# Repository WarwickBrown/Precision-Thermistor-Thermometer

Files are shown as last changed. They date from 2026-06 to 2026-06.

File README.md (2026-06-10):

# Precision Thermistor Thermometer

A two-channel, sub-millikelvin-class temperature measurement and logging
instrument built around a Raspberry Pi Pico W and a 16-bit ADS1115 ADC, using
matched 100 kΩ NTC thermistors in differential Wheatstone half-bridges.

It was developed as the instrumentation for a passively temperature-stabilised
enclosure used in a photonic reservoir-computing experiment. In that experiment
a multimode fibre acts as the nonlinear mixing medium, and its refractive index
(and therefore the computation it performs) is temperature-sensitive.
Characterising and controlling that thermal environment is what this instrument
is for.

The work is part of an MSc (Electrical Engineering) research project at the
University of the Witwatersrand, supervised by Prof. Mitchell Cox. The research
title is not finalised yet.

> **Status: v1.0.** A working two-channel instrument on soldered stripboard,
> housed in a 3D-printed enclosure. The thermistors are characterised, the two
> channels are matched, and a bonded-probe run shows the A−B difference holding to
> about 0.5 to 0.8 mK, with each probe to about 0.5 mK. See
> [Project status](#project-status).

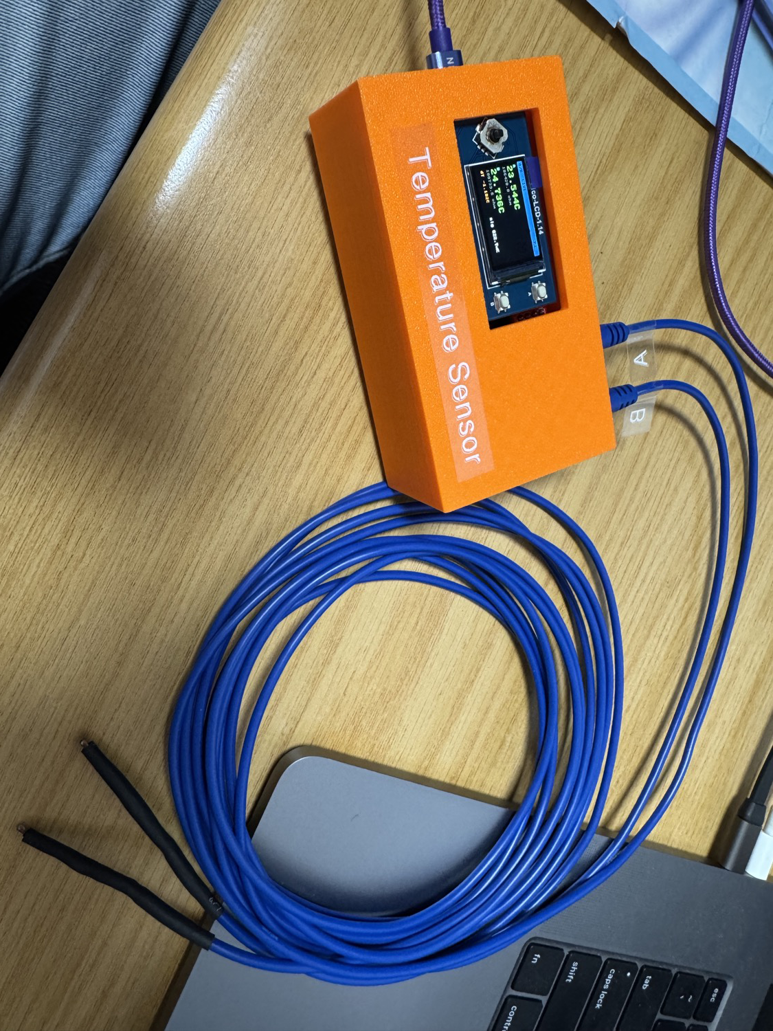
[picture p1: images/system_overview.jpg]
Two-channel thermistor thermometer


*Pico W and ADS1115 differential front-end with a Pico-LCD-1.14, soldered onto
stripboard, with both NTC probes on shielded cable.*

---

## Why this design

The goal was to find out, cheaply, how much temperature resolution is actually
achievable with a commodity 16-bit ADC before committing to a more complex and
more expensive 24-bit sigma-delta design (the ADS1220). Rather than assume the
24-bit part is necessary, this project proves out the 16-bit approach end to end
and measures its real noise floor.

The design decisions and the reasoning behind them are written up in
[`docs/design_notes.md`](docs/design_notes.md).

---

## How it works

```
            +3V3 (or ADC_VREF)
                 │
     ┌───────────┴───────────┐         (one half-bridge per channel)
     │                       │
    R_a (100k)              R_top (100k)
     │                       │
   NODE_A ───► AINP        NODE_B ───► AINN     ADS1115 reads (AINP − AINN)
     │                       │                  differentially, PGA-amplified
    R_b (100k)              NTC (100k, on cable)
     │                       │
    GND                     GND
```

* Each thermistor sits in its own differential half-bridge. The bridge output
  is about 0 V at balance (around 25 °C), so the ADC's smallest range
  (±0.256 V, PGA = 16) can be used for maximum resolution around the operating
  point.
* The ADS1115 has two differential pairs, so two probes are read: channel 1 is
  AIN0−AIN1 and channel 2 is AIN2−AIN3.
* Resistance is recovered from the measured differential voltage and then
  converted to temperature with a narrow-range B-model fit (see
  [Calibration](#calibration)).
* A Waveshare Pico-LCD-1.14 provides a multi-page live UI. Readings also stream
  as CSV over USB serial for logging.

### Resolution (theoretical)

| Quantity | Value |
|---|---|
| Bridge sensitivity (V_exc = 3.3 V) | ≈ 36.6 mV/K |
| ADS1115 LSB at PGA = 16 (±0.256 V) | 7.81 µV |
| **Resolution** | **≈ 0.21 mK / LSB** |
| Usable span at PGA = 16 | ≈ ±7 K around bridge balance |

These figures are derived and verified by round-trip simulation in
[`docs/design_notes.md`](docs/design_notes.md). The full error budget, which
separates the theoretical precision (tens of µK) from the reference-limited
absolute accuracy (about 0.1 °C), is in
[`docs/error_budget.md`](docs/error_budget.md).

---

## Measured performance

> Numbers marked _(prelim.)_ are early bench observations rather than a rigorous
> characterisation. The stability rows are from the bonded-probe calibration run.

| Metric | Value | Notes |
|---|---|---|
| Single-shot noise, settled (breadboard) | ~±4 mK p-p _(prelim., eyeballed)_ | continuous excitation, no RC filter |
| Rolling σ (32-sample), simulated 3 mK input | ~2.4 mK | sanity check of stats pipeline |
| Thermistor B-value match (A vs B) | 0.1 % | 3816.6 K vs 3820.8 K |
| Thermistor R₀ match (A vs B) | 0.3 % | ~99.9 kΩ vs ~99.6 kΩ at 25 °C |
| Absolute accuracy | ~0.1 °C | limited by reference probe (UNI-T UT71B) |
| Single-channel noise (1σ, single sample) | ~0.4 to 0.6 mK _(calibration run)_ | A ~0.6, B ~0.4, box drift removed |
| Differential A−B stability (Allan) | ~0.5 to 0.8 mK _(calibration run)_ | bonded probes, see [calibration results](docs/calibration/calibration_run_results.md) |
| Absolute long-term stability | reference-limited | bounded by the thermal environment and reference resistors, not the ADC |

A note on accuracy versus precision. The ~0.1 °C absolute figure is set by the
reference thermometer used during calibration. The instrument's relative
stability, which is the quantity that matters for thermal control, is far better.
The bonded-probe run shows the A−B difference holding to about 0.5 to 0.8 mK and
each probe to about 0.5 mK (see the
[calibration results](docs/calibration/calibration_run_results.md)). Pushing the
absolute single-channel figure lower would need a more stable thermal reference
than was available, since it is bounded by the environment rather than the ADC.

---

## Repository layout

```
precision-thermistor-thermometer/
├── README.md                 ← this file
├── LICENSE
├── CITATION.cff              ← how to cite this work
├── run.sh                    ← host helper: setup, flash, log, analyse
├── firmware/                 ← MicroPython for the Pico W
│   ├── config.py             ← all tunable constants (QUIET/FAST profiles, calibration)
│   ├── ads1115.py            ← minimal differential ADS1115 driver
│   ├── bridge.py             ← bridge maths + B-model / Steinhart-Hart
│   ├── sampling.py           ← runtime QUIET/FAST sampling-profile switch
│   ├── ds18b20_reader.py     ← optional 1-Wire ambient sensor
│   ├── lcd_1inch14.py        ← Waveshare Pico-LCD-1.14 driver (bundled)
│   ├── display.py            ← multi-page LCD UI (KEY A/B navigated)
│   └── main.py               ← measurement loop (USB + flash CSV logging)
├── hardware/
│   ├── ADS1115BasicDesign.*  ← KiCad schematic + BOM (draws an optional DS18B20 not fitted here)
│   ├── schematic_bridge.png  ← bridge + ADC front-end
│   ├── netlist.md            ← full from-to netlist
│   └── bom.md                ← bill of materials
├── docs/
│   ├── user_manual.md        ← how to run the device (screens, buttons, output)
│   ├── design_notes.md       ← design rationale + noise budget
│   ├── error_budget.md       ← theoretical accuracy vs precision, full budget
│   ├── calibration_procedure.md ← how to calibrate and match the two channels
│   ├── characterisation.md   ← thermistor calibration write-up
│   ├── calibration/          ← (T,R) sweep, fit workbook, channel-matching run + results
│   └── build_log.md          ← chronological bring-up / debugging notes
├── tools/
│   ├── serial_logger.py      ← capture the USB CSV stream to a host file (+ live plot)
│   ├── analyse_log.py        ← off-Pico stability / Allan-deviation analysis
│   └── requirements.txt      ← host-side Python dependencies
├── enclosure/                ← 3D-printed cover (Fusion 360 + STEP + STL)
│   ├── cover.f3d
│   ├── cover.step
│   └── cover.stl
├── data/                     ← logged runs (CSV)
└── images/                   ← photos, screenshots
```

---

## Quick start

1. Flash MicroPython for the Pico W (the `.uf2` from micropython.org).
2. Copy everything in [`firmware/`](firmware/) to the Pico's root. The Waveshare
   `lcd_1inch14.py` driver is bundled, so nothing else needs downloading. Thonny
   works, but `mpremote` copies the whole folder in one go
   (`mpremote connect auto cp firmware/*.py :` then `mpremote reset`), and
   `mpremote mount firmware` runs the code straight off your computer while you
   develop, with no copying.
3. Edit [`firmware/config.py`](firmware/config.py): set your measured excitation
   voltage, per-channel resistor values, and thermistor coefficients. Choose a
   boot `MODE`. `'logging'` starts in the quiet, roughly 1 mK QUIET profile and
   `'live'` starts in the fast FAST profile. You can switch between them at any
   time by long-pressing the joystick (see [Sampling profiles](#sampling-profiles)).
4. Reset the Pico. `main.py` runs automatically. Readings appear on the LCD,
   stream as CSV over USB serial, and, when `LOG_TO_FLASH` is set, are appended
   to `log.csv` on the Pico's flash so a run survives a USB disconnect.
5. Capture a run live on the computer with
   [`tools/serial_logger.py`](tools/serial_logger.py), or pull `log.csv` off the
   Pico's flash. Then analyse stability with
   [`tools/analyse_log.py`](tools/analyse_log.py) (see
   [Logging and analysis](#logging-and-analysis)).

The chronological bring-up, including the debugging dead-ends, is in
[`docs/build_log.md`](docs/build_log.md).

---

## Host tools (one-time setup)

The off-Pico steps (uploading the firmware, capturing, plotting, analysis) are
wrapped by [`run.sh`](run.sh), which keeps their Python dependencies in a
self-contained `.venv` so nothing is installed into your system Python:

```
./run.sh setup                          # once: create .venv and install the tools
./run.sh flash                          # copy firmware/ to the Pico and reboot it
./run.sh log                            # capture the USB CSV into data/ (Ctrl-C to stop)
./run.sh log --plot                     # ... and draw a live chart
./run.sh analyse data/log_YYYY..._.csv  # stability / Allan-deviation analysis
./run.sh pull-log                       # copy the Pico's flash log.csv into data/
./run.sh clear-log                      # wipe the Pico's flash log.csv (asks first)
```

Only one program can use the USB port at a time, so close Thonny or any serial
monitor before `flash` or `log`. The tools under [`tools/`](tools/) can also be
run directly if you prefer (Windows users without bash can create the venv with
`python -m venv .venv` and `pip install -r tools/requirements.txt`).

---

## The display

New to the device? The [user manual](docs/user_manual.md) walks through the
screens, the buttons, the update cadence, and how to read the data on a
connected computer.

Five pages, moved through with **KEY A** (next) and **KEY B** (previous). The
joystick LEFT / RIGHT pages too, as a backup.

| Page | Shows |
|---|---|
| **LIVE** | Both probes in large type: temperature, resistance, ΔT, rolling σ |
| **AVERAGES** | Rolling mean over a short and a long window, per probe, plus A−B |
| **TREND** | Scrolling chart of A and B temperature (shared autoscale) |
| **DELTA** | Scrolling chart of A−B (common-mode-cancelled, most sensitive) |
| **STATS** | Mean, σ, min-max span, drift rate, STABLE/SETTLING flag |

The rest of the controls sit on the joystick. UP cycles the backlight (full,
dim, off), which matters because the backlight is a heat source near the
sensors. DOWN resets the statistics and history. A short press of the joystick
centre toggles a hold/freeze, and a long press switches the sampling profile
live (see [Sampling profiles](#sampling-profiles)).

<p align="center">
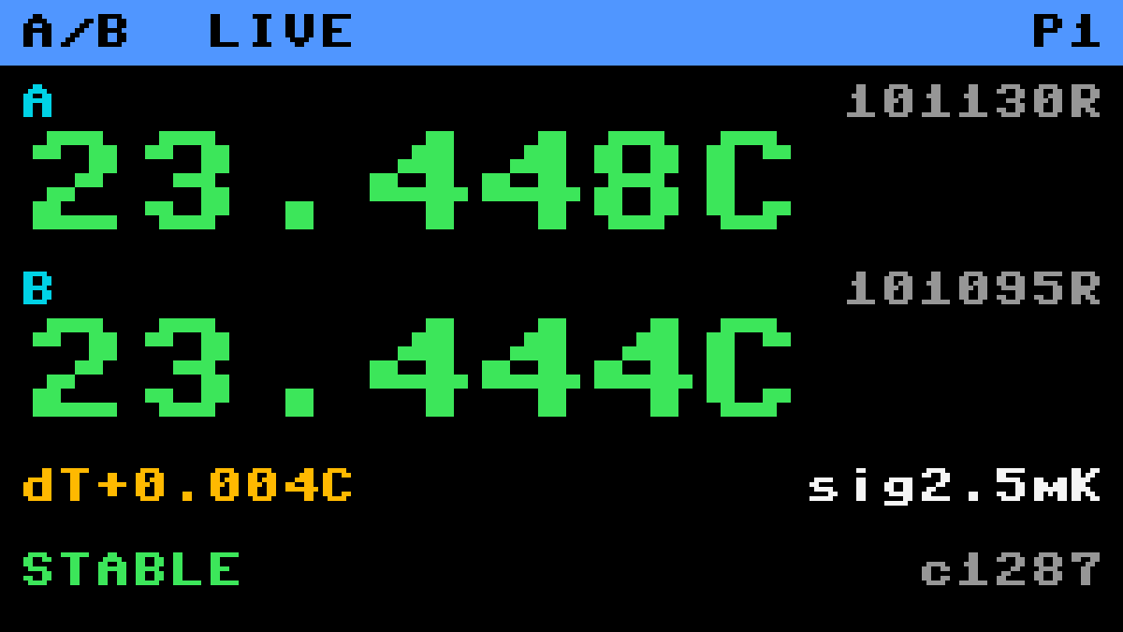
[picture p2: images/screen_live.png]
LIVE page
  
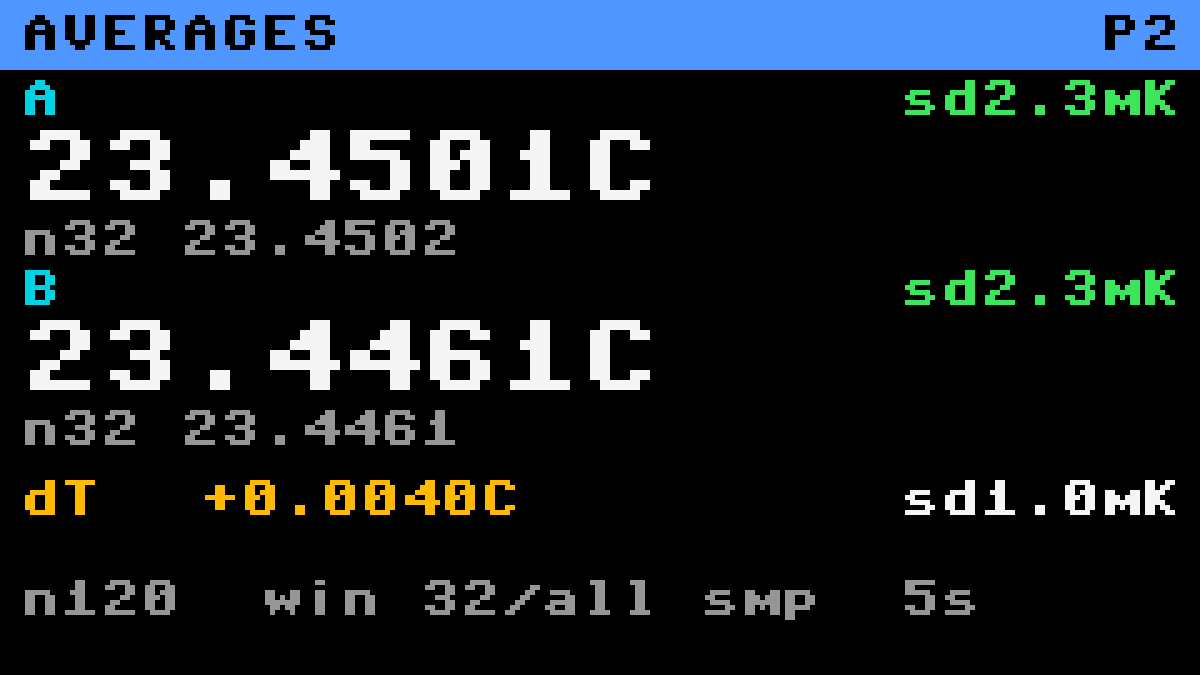
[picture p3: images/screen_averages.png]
AVERAGES page
  
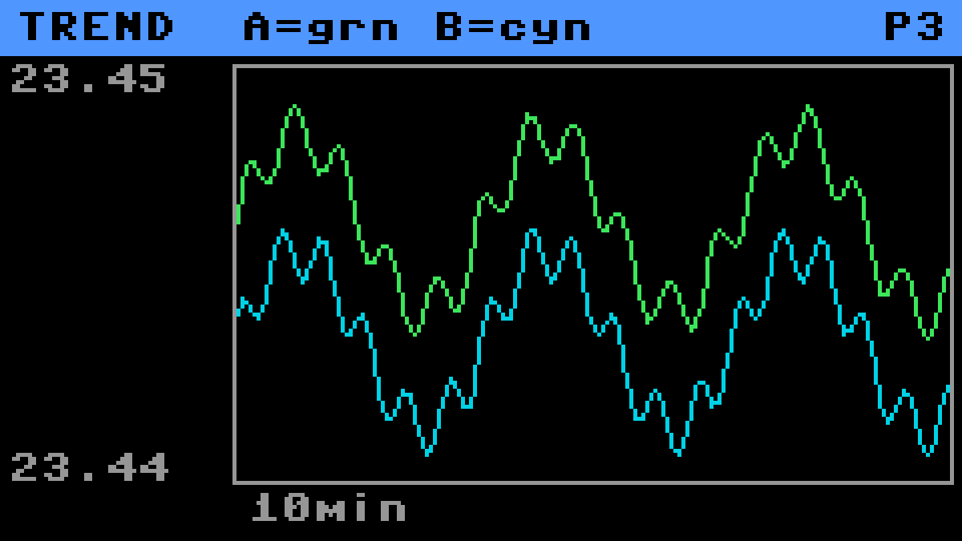
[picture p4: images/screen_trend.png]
TREND page
  
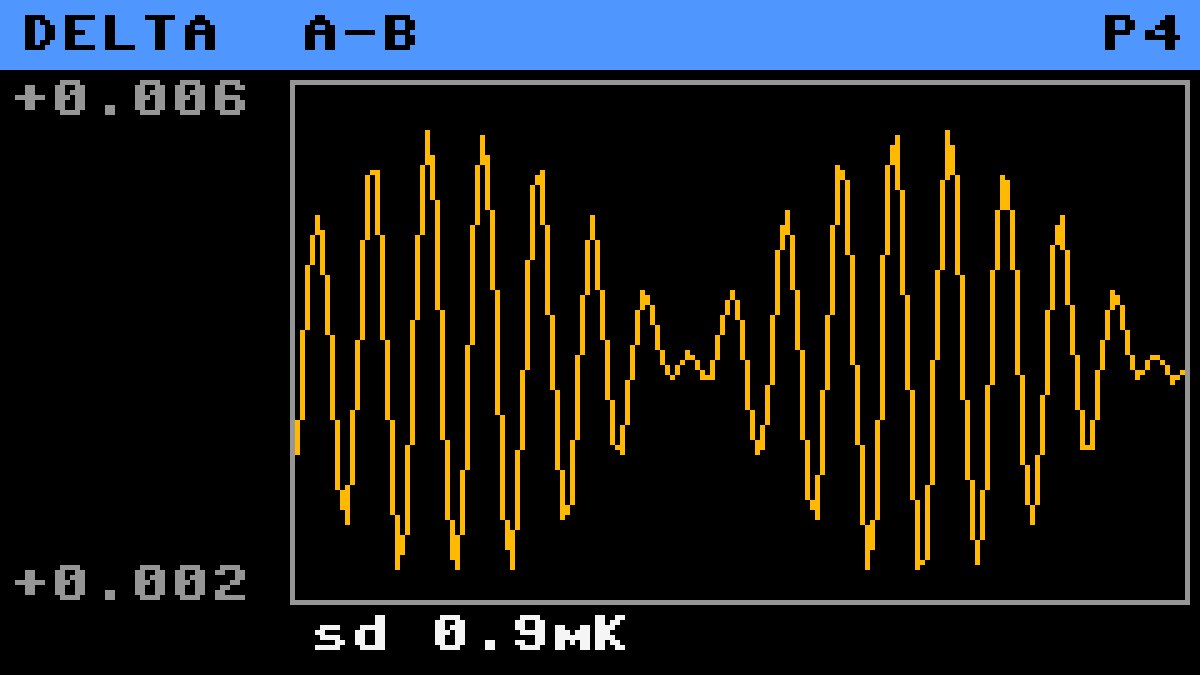
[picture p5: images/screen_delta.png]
DELTA page
  
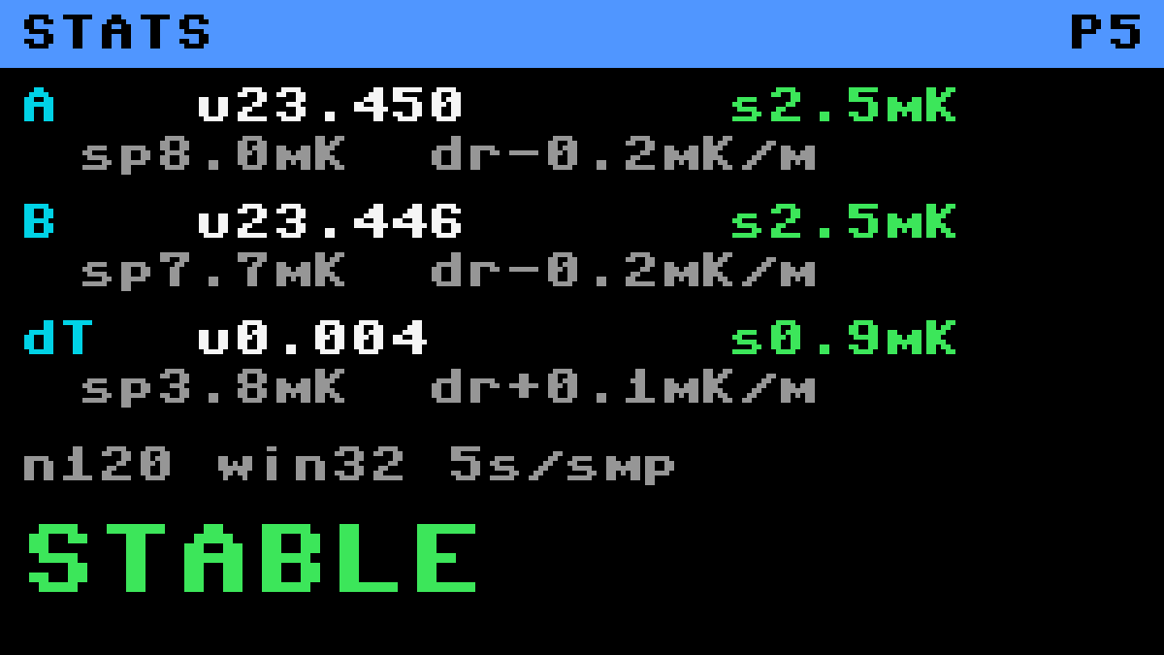
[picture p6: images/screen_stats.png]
STATS page
  
</p>

*The LIVE, AVERAGES, TREND, DELTA and STATS pages, rendered from the firmware
display layout using the panel's own 8x8 font, so they match the LCD pixel for
pixel. The values shown are illustrative.*

## Sampling profiles

The instrument carries two sampling profiles and switches between them at
runtime, with no reflash, by long-pressing the joystick centre. A FAST badge
shows in the header when the fast profile is active.

| Profile | Averages | Rate | PGA | Cycle | For |
|---|---|---|---|---|---|
| **QUIET** | 16 | 8 SPS | ±0.256 V | 5 s | the quiet, roughly 1 mK logging setup |
| **FAST** | 4 | 475 SPS | ±2.048 V | 0.2 s (≈5 Hz) | watching the screen in near real time |

`config.MODE` chooses which one is active at boot. Both profiles are defined in
[`firmware/config.py`](firmware/config.py), so the averages, rate, range, cycle
time, and settle wait of either can be tuned there. To go faster than 5 Hz, lower
the FAST `period_s` toward about 0.1.

---

## Logging and analysis

Each cycle the firmware emits one CSV row, both over USB serial and, when
`LOG_TO_FLASH` is set, appended to `log.csv` on the Pico's flash. The columns
are:

```
cycle, t_s, vdiff1_uv, r1_ohm, t1_c, vdiff2_uv, r2_ohm, t2_c, t_amb_c
```

The serial stream is the easy way to capture a run straight onto the connected
computer in real time. `serial_logger.py` auto-detects the Pico's port, saves a
timestamped file under `data/`, appends a `host_time` wall-clock column to each
row so the data lines up with other measurements, and can draw a live chart:

```
python tools/serial_logger.py            # capture to data/, echo to screen
python tools/serial_logger.py --plot     # also show a live temperature chart
```

The capture runs as long as you like and reconnects on its own if the USB drops,
while the live chart keeps a rolling window of recent points. The flash log is
the backup that survives a USB disconnect. Either way, copy the
resulting CSV onto a computer and run the off-Pico analysis tool:

```
python tools/analyse_log.py log.csv --settle-min 10
```

It prints per-channel statistics (mean, σ, peak-to-peak, drift), the
common-mode-cancelled A−B difference channel, and an overlapping Allan deviation
against averaging time τ. The minimum of the Allan curve is the headline number
for this project. It gives the best achievable stability and the averaging time
that reaches it, which is the direct answer to the question "is 16-bit enough?".
The tool needs `numpy` and `matplotlib`.

---

## Calibration

Thermistors are characterised individually against a UNI-T UT71B reference and
then fitted with a two-parameter B-model tuned for the 10 to 30 °C operating range:

```
T(°C) = B / (ln R − intercept) − 273.15
```

| Probe | B (K) | intercept | R₀ @ 25 °C |
|---|---|---|---|
| A (NTC-01) | 3816.56 | −1.288504 | ~99.9 kΩ |
| B (NTC-02) | 3820.82 | −1.306170 | ~99.6 kΩ |

For relative precision you usually do not need that absolute calibration, or a
reference thermometer at all. You only need the two channels to agree when both
probes are at the same temperature. Bond the probe beads together, let them
settle, read the steady A−B on the AVERAGES screen, and set the per-channel
`CH1_T_OFFSET` / `CH2_T_OFFSET` trims to zero it. The full step-by-step is in
[`docs/calibration_procedure.md`](docs/calibration_procedure.md). On this build
the channels are already matched: a bonded-probe run measured A−B at +133.5 mK,
now trimmed to within 0.1 mK (see
[calibration results](docs/calibration/calibration_run_results.md)).

The absolute method, residuals, and raw sweep data are in
[`docs/characterisation.md`](docs/characterisation.md) and
[`docs/calibration/`](docs/calibration/) (fit workbook
`V2_Thermistor_Measurement.xlsx`).

---

## Project status

- [x] Differential bridge + ADS1115 front-end designed and simulated
- [x] Single-channel bring-up on breadboard
- [x] Two-channel (Option C) differential operation
- [x] Thermistor characterisation (B-model)
- [x] Channel matching (A−B offset trimmed from a bonded-probe run)
- [x] Soldered onto stripboard with RC input filters + star ground
- [x] Multi-page LCD UI
- [x] On-Pico flash logging + off-Pico Allan-deviation analysis tool
- [x] 3D-printed enclosure modelled and printed (fit being refined)
- [x] Differential stability measured (A−B sub-millikelvin, bonded-probe run)
- [x] 16-bit confirmed sufficient for the differential measurement, so the ADS1220 is not needed

The absolute long-term stability is bounded by the thermal environment and the
reference resistors rather than the ADC, so characterising it below the drift of
the box used here would require a more stable reference.

---

## Future improvements

Out of scope for v1.0, but worth noting:

- **Pulsed excitation** with a logic-level PMOS, to cut the ~27 mK self-heating
  offset (deferred because only a non-logic-level part was available, see the
  [design notes](docs/design_notes.md)).
- **Absolute single-channel stability** characterisation, which would need a
  thermal reference more stable than the box used here.
- **Per-channel absolute recalibration** against a better reference, to improve
  the ~0.1 °C absolute accuracy.
- **WiFi/NTP timestamps** on the Pico W, so the standalone flash log carries
  absolute time without the host capture.

---

## License

MIT. See [LICENSE](LICENSE).

## Acknowledgements

Built at the University of the Witwatersrand as part of an MSc (Electrical
Engineering) project supervised by Prof. Mitchell Cox, as the instrumentation
for a photonic reservoir-computing experiment. The 3D-printed enclosure was
designed by Matthew Maccelari. The firmware and circuit were developed
iteratively on the bench. See [`docs/build_log.md`](docs/build_log.md) for the
full bring-up story, including the debugging dead-ends.

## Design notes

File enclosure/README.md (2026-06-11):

# Enclosure

3D-printed cover for the instrument (Pico + LCD + stripboard), designed by
**Matthew Maccelari**.

Source CAD and meshes:

| File | Format |
|---|---|
| `cover.f3d` | Fusion 360 source |
| `cover.step` | portable STEP solid (for other CAD tools) |
| `cover.stl` | mesh, ready to slice and print |

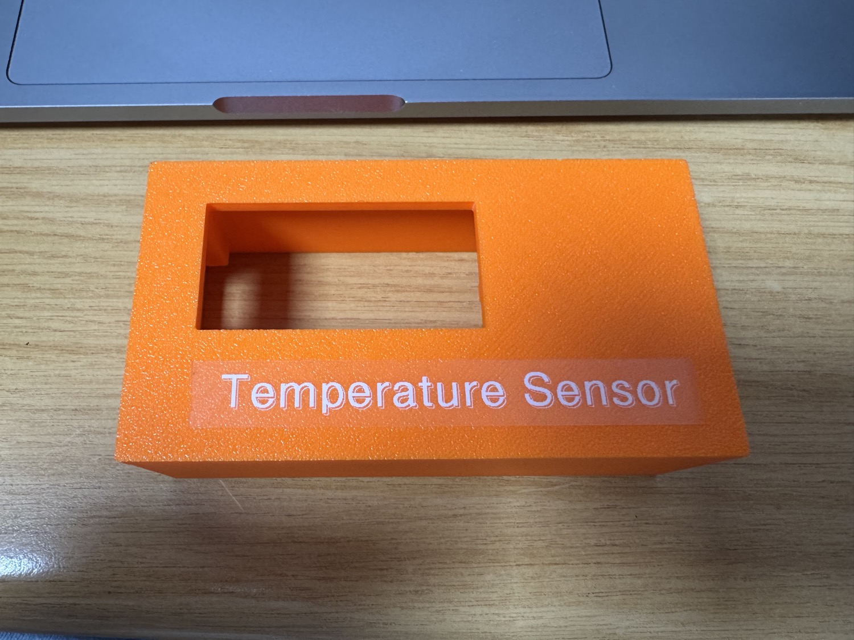
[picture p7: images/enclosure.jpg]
3D-printed enclosure, top with the LCD window and label


<p align="center">
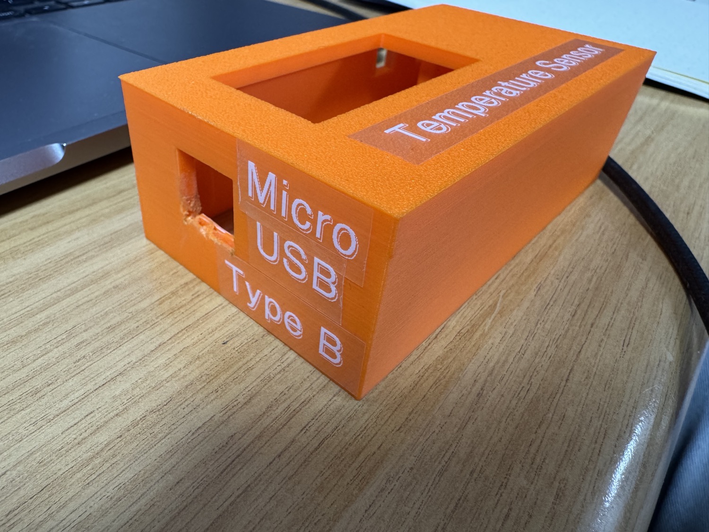
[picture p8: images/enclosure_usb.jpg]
USB Type-B port side
  
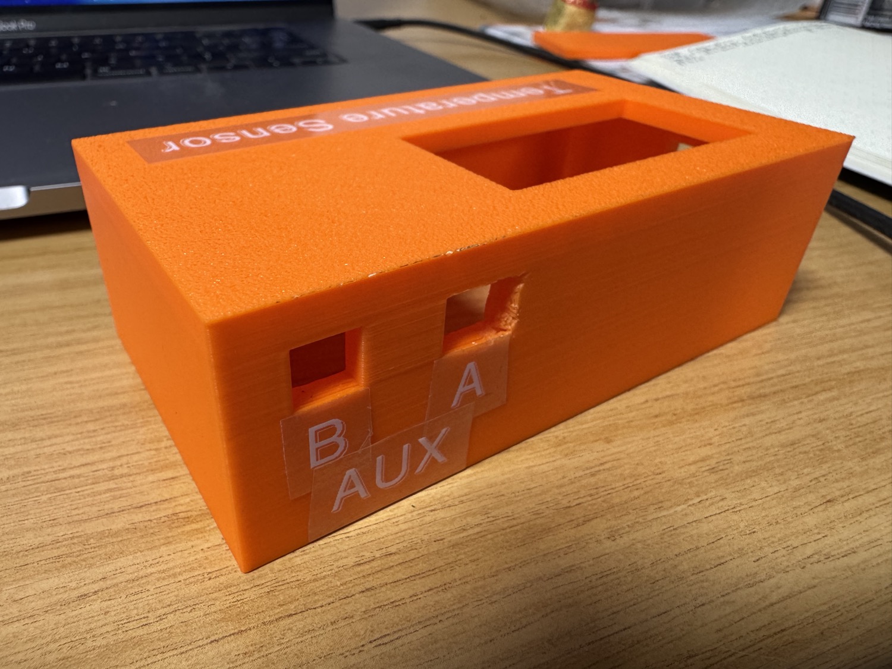
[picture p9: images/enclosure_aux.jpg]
AUX side with A / B probe jacks
  
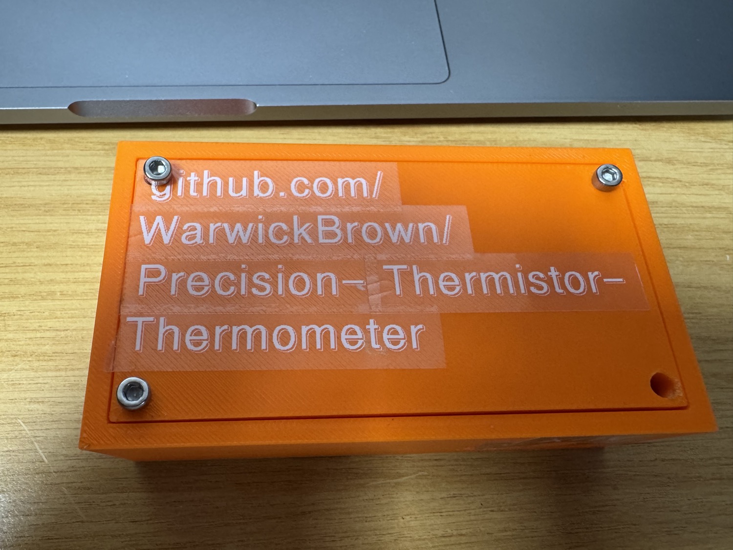
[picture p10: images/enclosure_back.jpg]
base, engraved with the repo URL
  
</p>

*USB side, the labelled A / B AUX jacks, and the engraved base.*

## Note

The 3D print is not perfect and adjustments need to be manually made to the hole sizes when fitting the circuit board into the enclosure.

M3 10mm hole inserts should be sunk into the plastic and M3 20mm bolts can be used to screw it all down.

## Design considerations

- **LCD on the lid**, board inside, which keeps the screen visible while the
  sensors stay enclosed.
- **Backlight heat:** the LCD backlight is the largest local heat source. Keep
  it physically away from the thermistor cable entries, and note the firmware
  can dim/disable the backlight (KEY A) during sensitive runs.
- **Cable pass-throughs** for the two thermistor leads (audio jacks) and USB.
- **Non-enclosed reference-resistor cluster** sits with the warm digital
  section, because thermal gradients across the bridge resistors appear as
  measurement error.
- **Female AUX daughter board supports** have been added so that the small boards do not flex. Glue the blocks onto the Veroboard and Prestik them to the top so the boards don't move. A support has been added behind the boards to support the insert force.

Most recent CAD file uploaded 11/06/2026 (v3)

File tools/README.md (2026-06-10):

# Tools

Off-Pico helpers that run on a normal computer rather than on the
microcontroller. Install their dependencies once with:

```
pip install -r tools/requirements.txt
```

## `serial_logger.py`

Captures the CSV the firmware streams over USB serial straight onto the host
computer. It auto-detects the Pico's serial port, echoes the stream to the
screen, and saves it to a timestamped file in `data/` that you can then feed to
`analyse_log.py`. Each row gets a `host_time` wall-clock column appended (last
field) so the data can be matched to other measurements taken on the same
computer. With `--plot` it also draws a live temperature chart. Needs `pyserial`
(and `matplotlib` only for `--plot`).

```
python tools/serial_logger.py                 # auto-detect port, save to data/
python tools/serial_logger.py --list          # list serial ports and exit
python tools/serial_logger.py --port COM5     # choose the port yourself
python tools/serial_logger.py --plot          # also draw a live chart
python tools/serial_logger.py --plot-points 6000  # keep more points on the chart
python tools/serial_logger.py --out run1.csv  # choose the output file
python tools/serial_logger.py --no-file       # echo only, do not save
python tools/serial_logger.py --no-timestamp  # do not append host_time
```

Notes:

* The capture is unlimited. It runs until you stop it with Ctrl-C, bounded only
  by disk space, and it reconnects on its own if the USB drops or the Pico
  resets, carrying on into the same file.
* The live chart shows a rolling window of the most recent points
  (`--plot-points`, default 3000) so memory and redraw stay flat over long runs.
  Everything is still saved to the file regardless of what the chart shows.
* The appended `host_time` column does not disturb `analyse_log.py`, which reads
  only the fixed firmware columns and ignores the extra field.
* The Pico's own flash log has no `host_time`, only the data and `t_s`, so it
  stays compact. Absolute time comes from this host capture.

This complements the on-Pico flash log. The flash log survives a USB
disconnect, while the serial capture is the easy way to pull a long run onto the
computer in real time.

### If it is not writing to the file

Run it from the VS Code integrated terminal (`python tools/serial_logger.py`),
not the Run button, so you can see the output and press Ctrl-C to stop cleanly.
The tool prints the absolute save path on startup (`saving: ...`), which by
default is this repo's `data/` folder, not your current directory.

* **Nothing scrolls and the file ends up empty.** No data is reaching the
  computer. Only one program can hold a serial port at a time, so close Thonny,
  the VS Code MicroPico or Serial Monitor extension, and any other REPL first.
  Then reset the Pico so `main.py` is actually running and streaming, rather than
  sitting at the REPL. The tool now prints a hint if it connects but sees no data
  within five seconds.
* **"This tool needs pyserial".** Install it into the same interpreter VS Code is
  using. In the VS Code terminal run `python -m pip install pyserial` (or
  `pip install -r tools/requirements.txt`), making sure the interpreter shown in
  the terminal prompt is the one the Run button uses.

## `analyse_log.py`

Stability analysis for the CSV the firmware produces (`log.csv`, a flash dump,
or a `serial_logger.py` capture). It reports per-channel statistics, the
common-mode-cancelled A-B difference channel, and the overlapping Allan
deviation against averaging time tau. The minimum of that curve answers the
project's central question, "is 16-bit enough?". Needs `numpy` and `matplotlib`.

```
python tools/analyse_log.py log.csv                 # stats + Allan plot -> stability.png
python tools/analyse_log.py log.csv --settle-min 10 # drop the first 10 min (warm-up)
python tools/analyse_log.py log.csv --col t1_c      # analyse a single column
python tools/analyse_log.py log.csv --no-plot       # stats only
```

The expected CSV columns are:

```
cycle, t_s, vdiff1_uv, r1_ohm, t1_c, vdiff2_uv, r2_ohm, t2_c, t_amb_c
```

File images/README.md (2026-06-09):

# Images

Photos and screenshots used in the documentation.

## System photos

| File | Shot |
|---|---|
| `system_overview.jpg` | finished instrument in its enclosure with both probe cables (README hero) |
| `lcd_live.jpg` | the soldered stripboard build (Pico W, ADS1115, probes), with the earlier UI on screen |
| `probes.jpg` | the two NTC probe leads (tinned inner conductors of the shielded cable) |

## Screen renders

Rendered from the firmware display layout (`firmware/display.py`) using the
panel's own 8x8 font, so they match what the LCD shows pixel for pixel. The
values are illustrative. These replace the earlier screen photos, which were of
the previous smaller-font UI.

| File | Page |
|---|---|
| `screen_live.png` | LIVE, both probes large: T, R, ΔT, rolling σ |
| `screen_averages.png` | AVERAGES, rolling means over a short and a long window |
| `screen_trend.png` | TREND, scrolling A/B temperature chart |
| `screen_delta.png` | DELTA, scrolling A−B difference |
| `screen_stats.png` | STATS, mean, σ, span, drift, STABLE/SETTLING flag |

## Enclosure

| File | View |
|---|---|
| `enclosure.jpg` | top / lid, with the LCD window and "Temperature Sensor" label |
| `enclosure_usb.jpg` | USB Type-B port side |
| `enclosure_aux.jpg` | AUX side with the labelled A / B probe jacks |
| `enclosure_back.jpg` | base, engraved with the repository URL |

The calibration workbook lives under
[`../docs/calibration/`](../docs/calibration/). A bath/UT71B setup photo and a
residuals plot can be added there later. See that folder's README.

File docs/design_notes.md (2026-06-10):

# Design notes

The reasoning behind the circuit and firmware choices. This is the "why" rather
than the "how". See the README for usage and `build_log.md` for the
chronological bring-up.

## Goal

Determine how much temperature resolution a commodity 16-bit ADS1115 can deliver
in a thermistor bridge before committing to a 24-bit ADS1220. The worry is that
a 24-bit part may not yield usable extra bits once real-world noise is accounted
for, so the cheaper option is validated first.

## Sensor choice: 100 kΩ NTC

* High resistance means lead and contact resistance are negligible. A 1 m cable
  at about 0.2 Ω is roughly 2 ppm of a 100 kΩ sensor, so no Kelvin or 4-wire
  sensing is needed.
* Large dR/dT, about −4400 Ω/K near 25 °C (B ≈ 3820 K), gives strong
  sensitivity.

## Topology: differential half-bridge

Each probe sits in a half-bridge, and the ADC reads the difference between the
sense node and a reference node.

```
dV/dT ≈ (V_exc / 4) · (B / T²) ≈ V_exc · 11.1 mV/K
      ≈ 36.6 mV/K at V_exc = 3.3 V
```

Reading differentially (AINP − AINN) rather than single-ended does three things:

* it rejects excitation-supply noise as common-mode,
* it keeps the signal near 0 V at balance so PGA = 16 (±0.256 V) can be used,
* it uses the ADS1115's full ±32768 signed range.

## Noise / resolution budget

| Quantity | Value |
|---|---|
| LSB at PGA = 16 | 7.81 µV |
| ADS1115 input-referred noise (8 SPS) | ~2 µV RMS |
| Bridge sensitivity | 36.6 mV/K |
| **Resolution** | **0.21 mK / LSB** |
| **Noise floor (single sample)** | **~55 µK RMS** |
| Span at PGA = 16 | ±7 K around balance |

So resolution and the white-noise floor are comfortably sub-mK. The ~55 µK above
is the ADC-noise component alone. The combined single-sample floor including
quantisation is about 85 µK, and the full budget with the measured results is in
[`error_budget.md`](error_budget.md). The real limits are self-heating,
reference-resistor drift, and layout/EMI, which are addressed below.

## Excitation: continuous DC (pulsing deferred)

Pulsed excitation was planned to cut thermistor self-heating, switched by a
high-side PMOS. The only available PMOS was an IRFD9024, a standard-threshold
part rather than a logic-level one. At 3.3 V gate drive it never fully enhances
and sits in its linear region with a large, temperature-dependent on-resistance.
That would inject drift into V_exc that mimics a temperature signal, which is
worse for precision than the problem it solves.

The decision was to run continuous excitation. Self-heating (about 27 mK at
3.3 V across the sense leg) is a constant offset that calibration absorbs. It
only harms precision if the dissipation-to-environment coupling fluctuates,
which it does not inside the still air of the enclosure. Pulsing can be
revisited later with a proper logic-level PMOS. To reduce self-heating passively
without a switch, a series dropper resistor can lower V_exc (around 10x less
dissipation at about 1 V) at the cost of some sensitivity.

## Ratiometric-ish reference

The bridge is excited from the Pico's filtered `ADC_VREF` pin (or 3V3). The
ADS1115 has a fixed internal reference, so the measurement is not fully
ratiometric. True ratiometric operation (external VREF tied to the excitation)
is a reason to move to the ADS1220 later.

## Front-end filtering

A differential RC filter sits at each ADC input: 1 kΩ in series per line plus a
100 nF differential cap across the pair, with optional 10 nF common-mode caps to
ground. The corner is about 800 Hz, far above the thermal signal bandwidth and
far below mains hum, RF, and digital switching. The 1 kΩ is kept small so the
ADS1115's finite PGA input impedance (about 700 kΩ at PGA = 16) introduces only
a fraction of a percent of scale error, which calibration removes anyway. A
larger series R would interact badly with the switched-cap input.

## Grounding

Star ground: analog returns (bridge bottoms, ADC GND, decoupling, filter caps)
on one strip, digital returns (Pico, LCD, I²C) on another, and the two joined by
a single jumper at the ADS1115 GND pin. On stripboard, strip resistance (about
5 mΩ per 30 mm) means shared digital return current would inject µV-level errors
into the analog reference, which is why the two are kept separate.

## Calibration model

A two-parameter B-model over the operating range is used rather than full-range
Steinhart-Hart. It gives better residuals in the operating window, because the
extreme-temperature bath points were taken under non-equilibrium conditions and
added scatter, and it inverts trivially. Both models are implemented in
`bridge.py`, and `config.TEMP_MODEL` selects between them.

## Verification

The bridge inverse-maths and resolution were checked by round-trip simulation:
pick a true NTC resistance, compute the differential voltage the ADC would see,
run it back through the firmware maths, and confirm recovery. The firmware's
B-model and Steinhart-Hart conversions were checked against the characterisation
spreadsheet's own predicted temperatures and matched to the third decimal.

The common-mode rejection was later measured on a bonded-probe run: as the box
drifted about 190 mK, the A−B difference held to a sigma of 3 mK, roughly 18
times below either channel alone, confirming the design intent. See
[`calibration/calibration_run_results.md`](calibration/calibration_run_results.md).

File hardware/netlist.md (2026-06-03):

# Netlist (from-to)

Two-channel differential bridge (Option C), continuous excitation, breakout
ADS1115, RC input filters, and audio-jack thermistor connectors. Each row is a
net. Nets with more than two endpoints span multiple rows.

> The excitation switch (PMOS) is not populated, so the bridge tops are wired
> directly to the excitation rail. See `docs/design_notes.md` for why.

## Power / excitation

| Net | From | To |
|---|---|---|
| +3V3 | Pico 3V3(OUT) pin 36 | ADS1115 VDD |
| +3V3 | Pico 3V3(OUT) pin 36 | C1, C2 (decoupling) |
| V_EXC | Pico ADC_VREF pin 35 (or 3V3) | R1, R2 tops (bridge 1) |
| V_EXC | Pico ADC_VREF pin 35 (or 3V3) | R4, R6 tops (bridge 2) |

## Bridge 1 → channel 1 (Thermistor A)

| Net | From | To |
|---|---|---|
| NODE_A1 | R1 / R3 midpoint | R_filt1 → AIN0 |
| NODE_B1 | R2 / J1-Tip midpoint | R_filt2 → AIN1 |
| GND | R3 bottom | analog GND |
| GND | J1 Ring | analog GND |
| GND | J1 Sleeve (shield, board end only) | analog GND |

## Bridge 2 → channel 2 (Thermistor B)

| Net | From | To |
|---|---|---|
| NODE_A2 | R4 / R5 midpoint | R_filt3 → AIN2 |
| NODE_B2 | R6 / J2-Tip midpoint | R_filt4 → AIN3 |
| GND | R5 bottom | analog GND |
| GND | J2 Ring | analog GND |
| GND | J2 Sleeve | analog GND |

## RC input filter (per channel)

| Net | From | To |
|---|---|---|
| AIN0 | R_filt1 (1k) | ADS1115 AIN0, C_diff1 one side |
| AIN1 | R_filt2 (1k) | ADS1115 AIN1, C_diff1 other side |
| AIN2 | R_filt3 (1k) | ADS1115 AIN2, C_diff2 one side |
| AIN3 | R_filt4 (1k) | ADS1115 AIN3, C_diff2 other side |

C_diff (100 nF) goes across each input pair, at the IC. Optional C_cm (10 nF)
goes from each AIN pin to analog GND.

## I²C / control

| Net | From | To |
|---|---|---|
| SDA | ADS1115 SDA | Pico GP0 |
| SCL | ADS1115 SCL | Pico GP1 |
| ADDR | ADS1115 ADDR | GND (address 0x48) |
| (ALRT) | ADS1115 ALERT/RDY | Pico GP14 (optional DRDY) |

## Ground

Star point: a single jumper from the digital GND strip to the analog GND strip
at the ADS1115 GND pin. The analog strip carries the bridge bottoms, jack
returns, decoupling and filter-cap grounds, and the ADS1115 GND. The digital
strip carries the Pico and LCD grounds. Pico AGND (pin 33) is the tidy landing
point for the analog star.

## LCD (Waveshare Pico-LCD-1.14 HAT)

Stacks on the Pico header. It uses GP8-GP13 (SPI plus DC/CS/RST/BL) and
GP2/3/15/16/17/18/20 for the joystick and keys. It grounds through the header to
the Pico ground plane (the digital side of the star).

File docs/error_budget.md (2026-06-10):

# Theoretical accuracy and precision

This is the error budget for the instrument: where the numbers in the README
come from, and what limits each of them. It answers two separate questions that
are easy to confuse.

* **Accuracy** is how close a reading is to the true temperature on an absolute
  scale. For this instrument it is set almost entirely by the reference probe
  used during calibration, not by the electronics.
* **Precision** (resolution and short-term stability) is how small a *change* the
  instrument can resolve. This is what matters for thermal control, and it is far
  finer than the accuracy.

All figures below are derived from the design and the component datasheets. The
bonded-probe calibration run confirms them at the differential level (see the
measured results near the end of this document).

## Headline numbers

| Quantity | Value | Set by |
|---|---|---|
| Resolution | ≈ 0.21 mK / LSB | ADC LSB ÷ bridge sensitivity |
| Single-sample precision | ≈ 0.085 mK RMS | ADC noise + quantisation |
| Averaged precision (QUIET, 16×) | ≈ 0.02 mK RMS | white noise ÷ √N |
| Averaged precision (FAST, 4×) | ≈ 0.04 mK RMS | white noise ÷ √N |
| Absolute accuracy | ≈ 0.1 °C | UNI-T UT71B reference probe |

The gap between precision (tens of µK) and accuracy (about 0.1 °C) is roughly a
factor of a thousand. That gap is the whole point. This is a precision relative
thermometer, not an accurate absolute one.

## Where the resolution comes from

The half-bridge sensitivity is

```
S = dVdiff/dT = V_exc · B / (4 · T²)  ≈ 36 mV/K
```

at V_exc = 3.3 V near 25 °C. (The fitted B of 3820 K gives 35.5 mV/K, while a
nominal 100 kΩ NTC with B ≈ 3950 K gives 36.6 mV/K, so the figure is ~36 mV/K
either way.) The ADS1115 at PGA = 16 (±0.256 V) has an LSB of

```
LSB = 2 · 0.256 V / 65536 = 7.81 µV
```

so one LSB is `7.81 µV / 36 mV/K ≈ 0.21 mK`. The sensitivity falls slowly as the
probe moves away from 25 °C, so the resolution is best near the bridge balance
point and degrades gently towards the edges of the ±7 K usable span.

## Random noise (sets short-term precision)

These are uncorrelated sample to sample, so averaging N samples reduces them by
√N. The firmware does this in both profiles (16 averages in QUIET, 4 in FAST).

| Source | Per sample | Notes |
|---|---|---|
| ADC input-referred noise (~2 µV RMS at 8 SPS) | ≈ 56 µK | dominant white-noise term |
| Quantisation (LSB / √12) | ≈ 64 µK | inherent to a 16-bit conversion |
| Johnson noise of the 100 kΩ arms (~5 Hz ENBW) | ≈ 3 µK | well below the ADC floor |
| **Combined single sample** | **≈ 85 µK RMS** | root-sum-square of the above |
| Combined after 16× averaging (QUIET) | ≈ 21 µK | the ~1 mK profile has headroom to spare |
| Combined after 4× averaging (FAST) | ≈ 43 µK | still sub-0.1 mK |

Averaging only helps until drift takes over. The point where it stops helping,
and the best stability the instrument actually reaches, is exactly what the
overlapping Allan deviation in `tools/analyse_log.py` measures.

## Systematic and drift terms

These do not average away. Most are either constant (and so removed by
calibration) or slow drift that only matters over minutes to hours.

| Source | Magnitude | Affects | Constant or drift |
|---|---|---|---|
| Excitation (V_exc) noise and drift | rejected near balance | precision | the differential bridge cancels it as common-mode |
| Reference-resistor tolerance | calibrated out | accuracy | the resistors are measured and entered in `config.py` |
| Reference-resistor tempco (10 to 50 ppm/°C) | ≈ 0.2 to 1.2 mK per °C of *ambient* change | precision/drift | drift, largely cancelled in the A−B channel |
| ADC gain error (±0.15 % typ) | ≈ 1.5 mK per K of offset from balance | accuracy | near-constant, a scale error |
| ADC integral non-linearity (±1 LSB) | ≈ 0.21 mK | accuracy | near-constant |
| Self-heating of the NTC (~27 µW) | ≈ 27 mK offset | accuracy | constant in still air, calibrated out |
| Lead and contact resistance (~0.2 Ω) | ≈ 0.05 mK | accuracy | constant, negligible at 100 kΩ |
| B-model fit residual | ≈ 0.1 °C absolute | accuracy | set by the reference probe, not the slope |

The reference-resistor tempco is the main thing standing between the instrument
and microkelvin stability. A change in the ambient around the bridge resistors
shifts the balance point by `α · T² / B` per degree, which is about 0.6 mK per °C
for an ordinary 25 ppm/°C resistor. This is why the design keeps the reference
cluster isothermal and away from the LCD backlight, and why low-tempco resistors
are worth using.

## Why the differential design helps twice

* **Within a channel,** reading `AINP − AINN` makes excitation-supply noise a
  common-mode signal that the bridge rejects. Near balance the residual
  sensitivity to V_exc is close to zero.
* **Across channels,** the A−B difference cancels anything both probes see in
  common: shared ambient drift, shared resistor tempco, shared self-heating
  coupling. That is why A−B is the most stable channel and the best place to look
  for a small real signal against a drifting background.

## Measured so far (first calibration run)

A bonded-probe run in a temperature-controlled box gives the first real numbers
to set against the budget above (full write-up in
[`calibration/calibration_run_results.md`](calibration/calibration_run_results.md)):

| Quantity | Measured | Notes |
|---|---|---|
| Resolution | 0.21 mK/LSB | as designed |
| Single-channel noise (1σ, single sample) | ~0.4 to 0.6 mK | drift removed via successive differences (A ~0.6, B ~0.4), versus an as-measured Allan of ~0.8 mK inflated by box drift |
| Differential A−B stability | ~0.5 to 0.8 mK (Allan) | drift cancels, the real floor reached |
| Absolute accuracy | ~0.1 °C | reference-limited, unchanged by matching |

The single-channel noise is the short-term scatter once the box's own drift is
removed (the successive-difference estimate, which matches the A−B Allan
deviation to better than 0.01 mK). The raw single-channel Allan deviation on this
run was ~0.8 mK only because the box was still drifting.

**Used independently** (each probe as its own absolute thermometer), a channel
has a single-sample repeatability of about half a millikelvin, but its absolute
reading is only good to ~0.1 °C and its longer-term stability is set by ambient
and reference-resistor drift, not by ADC noise. **Used differentially** (A−B),
the common-mode rejection removes that drift and the pair reaches the
sub-millikelvin floor. The single-channel noise floor sits somewhere between the
differential result and the theoretical ~85 µK. Pinning it more precisely would
need a thermal reference more stable than the box used here, because the box
drift, not the ADC, sets the limit.

## Verification status

The resolution and the noise floor were checked by round-trip simulation (see
[`design_notes.md`](design_notes.md)) and confirmed at the differential level by
the bonded-probe calibration run. The per-channel absolute stability is bounded
by the thermal environment and the reference resistors rather than the ADC, so
characterising it below the available box drift would need a more stable
reference.

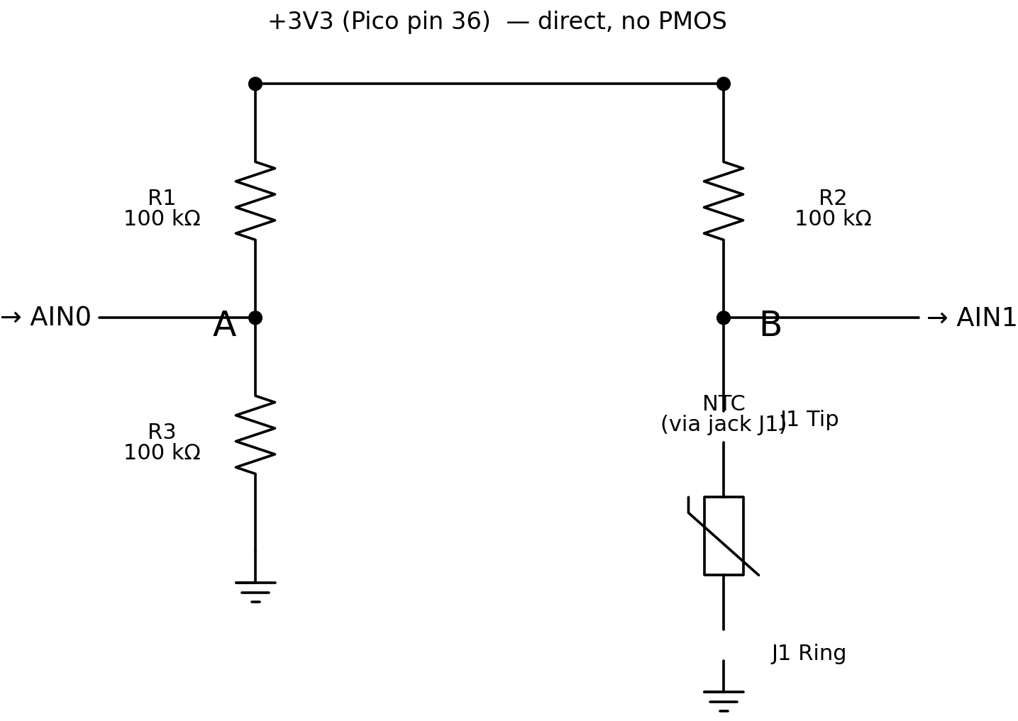
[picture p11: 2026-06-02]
hardware/schematic_bridge.png

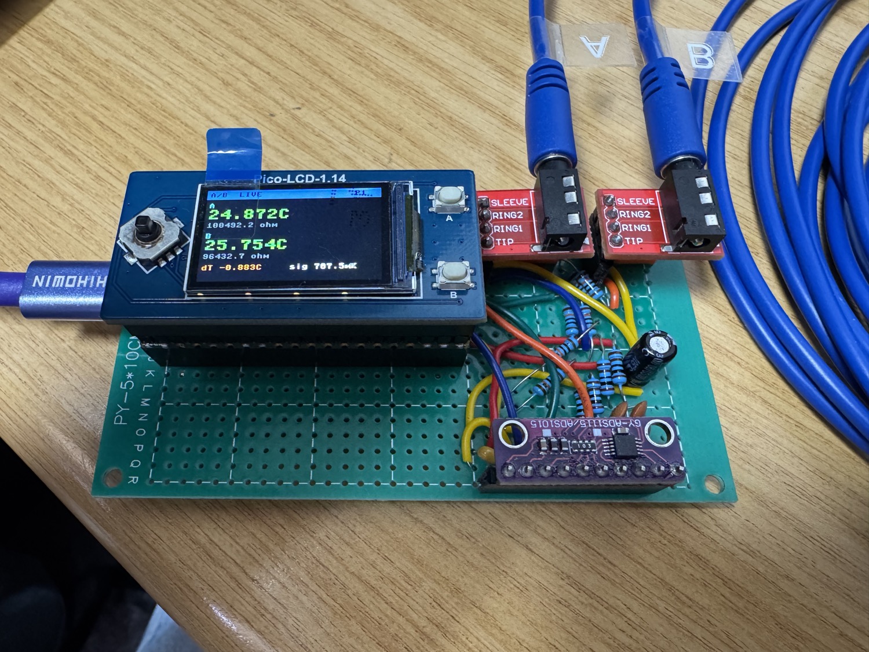
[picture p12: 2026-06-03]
images/lcd_live.jpg

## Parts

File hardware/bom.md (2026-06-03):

# Bill of materials

| Ref | Part | Value / spec | Notes |
|---|---|---|---|
| U1 | ADS1115 breakout | 16-bit I²C ADC | Adafruit 1085 or clone, on-board I²C pull-ups |
| U2 | Raspberry Pi Pico W | RP2040 + wireless | |
| LCD1 | Waveshare Pico-LCD-1.14 V2 | 240×135 ST7789, joystick + 2 keys | stacks on the Pico header |
| R1,R2,R3 | Resistor | 100 kΩ, 0.1 %, ≤25 ppm/K, thin-film | bridge 1, same reel/batch |
| R4,R5,R6 | Resistor | 100 kΩ, 0.1 %, ≤25 ppm/K, thin-film | bridge 2, same reel/batch |
| TH1 (A) | NTC thermistor | ~100 kΩ @ 25 °C, B ≈ 3817 K | characterised, on cable |
| TH2 (B) | NTC thermistor | ~100 kΩ @ 25 °C, B ≈ 3821 K | characterised, on cable |
| R_filt1-4 | Resistor | 1 kΩ, 1 %, thin-film | RC filter series, in signal path |
| C_diff1,2 | Capacitor | 100 nF, C0G/NP0 | RC filter differential, across AIN pairs |
| C_cm1-4 | Capacitor | 10 nF, C0G/NP0 | RC filter common-mode (optional) |
| C1 | Capacitor | 100 nF, X7R | ADS1115 decoupling, at VDD pin |
| C2 | Capacitor | 10 µF, X7R/X5R | bulk decoupling on rail |
| J1,J2 | TRS audio jack | 3.5 mm or 6.35 mm, gold contacts | thermistor connectors, label distinctly |
| (none) | Stripboard (Veroboard) | | analog + digital sections, star ground |
| (none) | Shielded twisted-pair cable | mic cable or similar | jack to thermistor runs |

### Not populated (design-time options)

| Ref | Part | Why omitted |
|---|---|---|
| Q1 | Logic-level PMOS | pulsed-excitation switch, deferred. Only a non-logic-level IRFD9024 was available, so continuous excitation is used instead |
| R_g1,R_g2 | 10 kΩ | PMOS gate drive (only if Q1 fitted) |
| U3, J3, R_pu1 | DS18B20 + 1-Wire jack + 4.7 kΩ pull-up | ambient 1-Wire sensor. Drawn in the KiCad schematic (`ADS1115BasicDesign`) as an optional addition, but not fitted in the build shown here. The firmware reads it if present (the `t_amb_c` column) and skips it otherwise |

### Calibration / test equipment

| Item | Use |
|---|---|
| UNI-T UT71B multimeter + K-type probe | thermistor characterisation reference |

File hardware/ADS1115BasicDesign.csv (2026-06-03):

Reference | Qty | Value | DNP | Exclude from BOM | Exclude from Board | Footprint | Datasheet
C1 | 1 | 100n
C2 | 1 | 10u
C_cm1,C_cm2,C_cm3,C_cm4 | 4 | 10nF
C_diff1,C_diff2 | 2 | 100nF
J1,J2,J3 | 3 | AudioJack3
R1,R2,R3,R4,R5,R6 | 6 | 100k 0.1%
R_filt1,R_filt2,R_filt3,R_filt4 | 4 | 1k 1%
R_pu1 | 1 | 4.7k 5%
TH1,TH2 | 2 | 100k
U1 | 1 | ADS1115IDGS |  |  |  | Package_SO:TSSOP-10_3x3mm_P0.5mm | http://www.ti.com/lit/ds/symlink/ads1113.pdf
U2 | 1 | Pico |  |  |  | RPi_Pico:RPi_Pico_SMD_TH

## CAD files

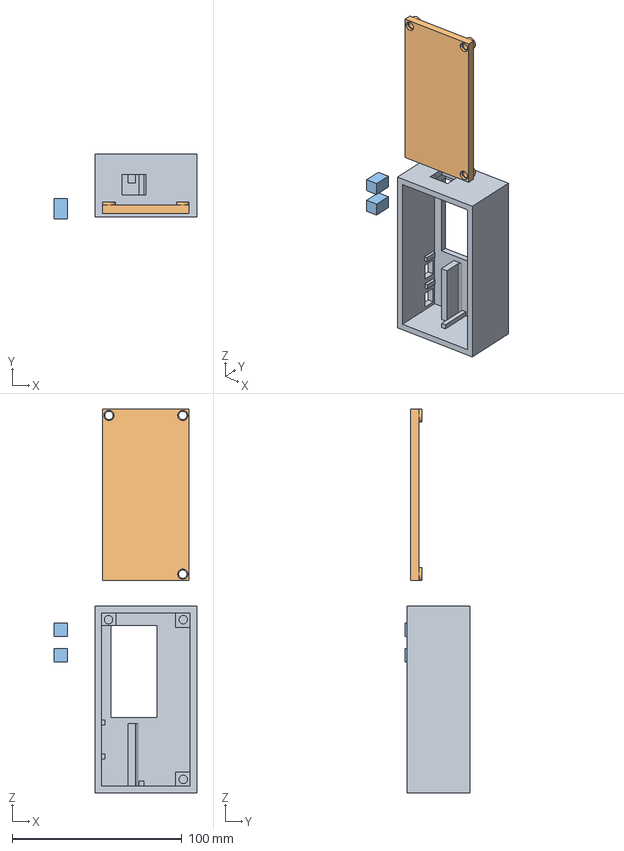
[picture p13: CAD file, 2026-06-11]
enclosure/cover.step
84.0 x 38.0 x 226.0 mm

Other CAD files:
enclosure/cover.f3d
enclosure/cover.stl

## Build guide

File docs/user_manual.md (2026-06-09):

# User manual

A short guide to running the thermometer day to day: what the screens show, what
the buttons do, how often it updates, and how to read the data on a connected
computer.

## Powering on

Plug the Pico into USB. The firmware (`main.py`) starts on its own.

* If the ADS1115 is not detected, the screen shows `Waiting for ADS1115...` and
  it keeps retrying. Check the I2C wiring if it sticks here.
* Once the ADC is found it runs a one-time self-check (reported over USB) and
  then shows the LIVE page. If a channel is railed it briefly shows
  `Bridge OUT OF RANGE`, which usually means a probe is unplugged or the range
  needs widening.

## How often it updates (read this first)

This is the thing that trips people up. The instrument takes one full reading per
**measurement cycle**, and the numbers on screen refresh once per cycle:

| Profile | Cycle | What it is for |
|---|---|---|
| **QUIET** | about every 5 seconds | the quiet, roughly 1 mK logging setup |
| **FAST** | about 5 times a second (5 Hz) | watching the screen in near real time |

So in QUIET the readings update only every 5 seconds or so. Between cycles the
last reading simply stays on screen. That is normal, not a frozen device. If you
want the numbers to move in near real time, switch to FAST (long-press the
joystick, see below) and a red **FAST** badge appears in the top right.

The buttons themselves respond immediately, during a measurement as well as
between them. The page also redraws the moment you press a button.

## The screens

Five pages. Move between them with **KEY A** (next) and **KEY B** (previous).

| Page | Shows |
|---|---|
| **LIVE** | Each probe in large type: temperature (°C, to 1 mK) and resistance (Ω). Below that the A-B difference (`dT`), the rolling noise (`sig`, in mK), a STABLE/SETTLING flag, and the cycle count. |
| **AVERAGES** | Per probe, the rolling mean over a long window (big) and a short window (small), plus the long-window noise (`sd`). Use this page when matching the probes (see calibration). |
| **TREND** | A scrolling chart of both temperatures, A in green and B in cyan, sharing an autoscaled axis. The hi/lo numbers are the axis range and the bottom number is the time span shown. |
| **DELTA** | A scrolling chart of A-B only. This is the most sensitive view because anything both probes share cancels out. |
| **STATS** | Per probe: mean (`u`), noise (`s`), min-to-max span, and drift rate. At the bottom, a large STABLE or SETTLING flag. |

STABLE means the recent noise has dropped below the settle threshold. SETTLING
means it is still moving.

## The controls

| Control | Action |
|---|---|
| **KEY A** | next page |
| **KEY B** | previous page |
| **Joystick LEFT / RIGHT** | previous / next page (backup for KEY A / KEY B) |
| **Joystick UP** | cycle the backlight: full, then dim, then off, then full |
| **Joystick DOWN** | reset the statistics, history, and min/max |
| **Joystick press (short tap)** | HOLD: freeze the charts and statistics so you can read them. The live numbers keep updating. Tap again to resume. A HOLD tag shows in the top right. |
| **Joystick press (long, about 1 second)** | switch the sampling profile between QUIET and FAST |

A couple of notes that match how it behaves:

* KEY A and KEY B are the most reliable way to change page. The joystick
  directions also work but are a little less positive.
* The backlight is a heat source close to the sensors, so turning it down or off
  with joystick UP is worth doing during a careful measurement.
* DOWN clears the running statistics and the chart history. Use it to start a
  fresh measurement window.

## Reading the data on a connected computer

Yes, the instrument streams its data out over the same USB cable. Each
measurement cycle it prints one line of CSV over USB serial (the Pico shows up as
a serial port, often named like `/dev/cu.usbmodem...` on macOS, `/dev/ttyACM0` on
Linux, or `COMx` on Windows). The baud rate does not matter for USB.

The columns are:

```
cycle, t_s, vdiff1_uv, r1_ohm, t1_c, vdiff2_uv, r2_ohm, t2_c, t_amb_c
```

`t_s` is seconds since the firmware started, which is fine for lining things up
within one run. For an absolute time you can match to other data you take, use
`serial_logger.py`: it appends a `host_time` column (your computer's wall-clock
time, to the millisecond) as the last field of every row, stamped the moment the
row arrives. The Pico has no clock of its own, so this host stamp is the reliable
way to get absolute time.

How long can it run? The saved file is unlimited, it keeps going until you stop
it with Ctrl-C, bounded only by disk space. If the USB is bumped or the Pico
resets, the capture reconnects on its own and carries on into the same file. With
`--plot` the chart shows a rolling window of the most recent points
(`--plot-points`, default 3000) so it stays fast over long runs, while the file
still keeps everything.

Three ways to see it, easiest first:

1. **The capture tool (recommended).** From the repo on the computer:
   ```
   python tools/serial_logger.py            # auto-detects the Pico, saves to data/
   python tools/serial_logger.py --plot     # also shows a live chart
   ```
   It finds the port, echoes the stream, and saves a timestamped CSV in `data/`
   that you can then run through `tools/analyse_log.py`.
2. **Thonny.** The Shell pane shows the CSV stream live, because the Pico is
   printing to its console. Good for a quick look.
3. **Any serial terminal** (screen, PuTTY, minicom) opened on the Pico's port.

There is also a backup copy on the Pico itself. With `LOG_TO_FLASH` on (the
default) the same CSV is appended to `log.csv` in the Pico's flash, so a run
survives a USB unplug. Pull that file off with Thonny or
`mpremote cp :log.csv .`. The flash log carries no `host_time`, only the data and
`t_s`, which keeps it compact. The absolute time is added by the host capture, so
you get both: a small on-device log and matchable timestamps in the saved file.

To turn the console stream on or off, set `LOG_TO_CONSOLE` in `config.py`. The
flash log is `LOG_TO_FLASH`.

## Quick troubleshooting

| Symptom | Cause and fix |
|---|---|
| Screen is dark | The backlight may be off. Press joystick UP to cycle it back to full. |
| Numbers only change every few seconds | That is the QUIET cycle. Long-press the joystick for FAST. |
| A page will not change | Use KEY A / KEY B, which are the most reliable. The joystick L/R are a backup. |
| Screen stuck on `Waiting for ADS1115` | The ADC is not on the I2C bus. Check SDA, SCL, power, ground, and the address pin. |
| `Bridge OUT OF RANGE` at start | A channel is railed, usually an unplugged or miswired probe, or the range is too small. See `config.py` (`MODE` / FSR). |
| A and B disagree at the same temperature | That is a matching offset. See [`calibration_procedure.md`](calibration_procedure.md). |

## Going further

* Matching the two probes and calibrating: [`calibration_procedure.md`](calibration_procedure.md).
* What the precision and accuracy actually are: [`error_budget.md`](error_budget.md).
* Analysing a logged run: [`../tools/README.md`](../tools/README.md).

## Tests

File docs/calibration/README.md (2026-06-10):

# Calibration data

Raw characterisation data and the fit for the two NTC probes, plus the
channel-matching run. The absolute write-up is in
[`../characterisation.md`](../characterisation.md), the channel-matching and
differential-stability results are in
[`calibration_run_results.md`](calibration_run_results.md), and the derived
coefficients and offsets live in [`../../firmware/config.py`](../../firmware/config.py).

## Contents

| File | What it is |
|---|---|
| `V2_Thermistor_Measurement.xlsx` | master workbook: the (T, R) sweep, the B-model fit, and residuals |
| `calibration_log.csv` | channel-matching run, both beads bonded in a temperature-controlled box |
| `calibration_run_stability.png` | time series and Allan deviation from that run |
| `calibration_run_results.md` | the channel offset, statistics and Allan deviation write-up |
| `sweep_raw.csv` *(optional)* | plain-text export of the (T, R) pairs, for tools that cannot read `.xlsx` |
| `residuals.png` *(optional)* | residuals-vs-temperature plot, if exported from the workbook |
| `setup.jpg` *(optional)* | photo of the water bath and UT71B reference during the sweep |

## (T, R) column format

Reference temperature in °C (UNI-T UT71B + K-type probe) paired with the
measured thermistor resistance in Ω. Only the points in the operating range are
used for the residual statistics. The bath extremes taken under non-equilibrium
settling are excluded, as explained in the write-up.

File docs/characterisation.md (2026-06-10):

# Thermistor characterisation

Both NTC thermistors were characterised before installation in the bridge, so
the R(T) curve is a property of the sensor alone and transfers to any downstream
circuit.

This is the absolute calibration. If you only want the two channels to agree at
rest (relative precision), you do not need this at all. See
[`calibration_procedure.md`](calibration_procedure.md) for the simpler matching
trim.

## Method

* **Reference:** UNI-T UT71B multimeter with its K-type thermocouple probe. The
  thermistor bead and the thermocouple tip were thermally coupled so they saw
  the same temperature.
* **Sweep:** a slowly cooling water bath provided a range of temperatures. The
  thermistor resistance and reference temperature were recorded as pairs once
  the rate of change was slow enough for both sensors to track together.
* **Fit window:** the model is fit to the settled middle of the sweep (roughly
  5 to 40 °C), and the residuals are then evaluated over the 10 to 30 °C operating
  range. The points at the cold and hot extremes were taken while the bath was
  still ramping, so they were excluded. They degraded the fit without
  representing the operating point.

## Model

Two-parameter B-model:

```
1/T = 1/T₀ + (1/B)·ln(R/R₀)     ⇔     T(°C) = B / (ln R − intercept) − 273.15
```

## Results

| Probe | B (K) | intercept | R₀ @ 25 °C | fit R² |
|---|---|---|---|---|
| A (NTC-01) | 3816.564 | −1.288504 | ~99.9 kΩ | ≥ 0.9996 |
| B (NTC-02) | 3820.824 | −1.306170 | ~99.6 kΩ | ≥ 0.9996 |

The two devices are closely matched, with B-values within 0.1 % and R₀ within
0.3 %. That is valuable for a two-channel differential instrument because both
channels then behave alike, and their difference (A−B) is especially clean.

The full sweep, the fit, and the residuals are in the workbook
[`calibration/V2_Thermistor_Measurement.xlsx`](calibration/V2_Thermistor_Measurement.xlsx).

## Accuracy vs precision

The residual RMS of the fit (about 0.1 °C) is the absolute accuracy floor, and
it is set by the UT71B thermocouple's resolution and absolute accuracy rather
than by the instrument's noise. The instrument's relative stability, meaning its
ability to detect small changes in temperature, is far finer and is limited by
ADC noise and bridge drift in the millikelvin range. The two figures describe
different things and should not be conflated.

A first bonded-probe run quantifies this gap: the A−B difference holds to about
0.5 to 0.8 mK while each channel alone is drift-limited, against the same
~0.1 °C absolute floor. See
[`calibration/calibration_run_results.md`](calibration/calibration_run_results.md).

## Files

* [`calibration/`](calibration/) holds the raw (T, R) sweep data, the fit
  workbook `V2_Thermistor_Measurement.xlsx`, and the residuals plot.
* Coefficients are entered in [`../firmware/config.py`](../firmware/config.py).

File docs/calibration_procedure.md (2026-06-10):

# Calibration procedure

How to calibrate your own build. There are three layers, and you only need as
many as you care about.

1. **Electrical setup** so the recovered resistance is right. One-time.
2. **Channel matching** so the two probes read the same value at rest. This is
   the precision-critical step and the easy one.
3. **Absolute calibration** so the readings are correct on a true scale.
   Optional, and only if you care about absolute accuracy.

The important thing to understand first: **for precision you do not need an
accurate reference thermometer at all.** You only need both probes at the same
temperature, which you can guarantee by bonding the two beads together. You never
have to know what that shared temperature actually is. See
[`error_budget.md`](error_budget.md) for why precision and accuracy are separate
here.

## 1. Electrical setup (one-time)

These make the resistance the firmware recovers match the real thermistor
resistance. Tolerances here largely cancel out in the matching step, but the
measurements are quick.

* Measure the excitation voltage at the bridge top node with a multimeter and
  put it in `config.V_EXC`.
* Measure each bridge resistor out of circuit (the top resistor and the two
  reference-leg resistors per channel) and enter them in `config.CH1_R_TOP`,
  `CH1_R_A`, `CH1_R_B`, and the `CH2_*` equivalents.

## 2. Match the two probes at rest (the precision trim)

The goal is that when both probes sit at the same temperature, A reads the same
as B, so the A-B difference channel sits at zero and a small real difference
shows up cleanly against it.

1. **Bring both probes to the same temperature.** Easiest first:
   * Bond the two beads in contact (twist or tape them together) and leave them
     in still air inside the enclosure.
   * Better, put both into one thermal mass, such as a metal block with two
     holes or a small sealed vial of water or oil, and let it sit insulated.
     Stir it, then leave it to settle.
   * Do this in the real operating configuration: same cable lengths, same
     enclosure, backlight at its normal setting. Anything that differs between
     the two channels and is not stable will show up as a false offset.
2. **Let it settle.** Watch the STATS page until it reads STABLE and the DELTA
   and AVERAGES pages show a flat A-B. This can take many minutes because of the
   thermal mass and the probes' own self-heating settling. Do not handle the
   probes while they settle.
3. **Read the steady difference.** On the AVERAGES page, read the long-window
   means of A and B and the dT value (dT = A - B). That dT is the offset to
   remove.
4. **Set the trim** in `config.py`. The offsets are added to the readings:
   * Split it evenly: `CH1_T_OFFSET = -dT/2` and `CH2_T_OFFSET = +dT/2`. This
     keeps both channels close to their average.
   * Or move one onto the other: `CH2_T_OFFSET = +dT` and `CH1_T_OFFSET = 0` if
     you would rather leave A as the trusted channel.
   * Sign check: if A reads higher than B then dT is positive, so you lower A
     and raise B.
5. **Reflash `config.py`, re-settle, and confirm** dT now sits near zero on the
   AVERAGES page. One pass is usually enough. Iterate once if a small residual
   remains.

Why a single point is enough: the two thermistors match to about 0.1 % in B and
0.3 % in R0, and the enclosure holds a narrow temperature range, so a single
offset keeps them matched across the whole operating window. The quality of the
match is then visible as the residual A-B sigma on the DELTA page, which is your
precision floor for the difference.

What this does not fix: slow drift over time, which is a thermal-design and
stability question that the Allan-deviation campaign quantifies, and absolute
accuracy, which is the next section.

Worked example: the first run gave a steady A−B of +133.5 mK, which was split
into `CH1_T_OFFSET = -0.0667` and `CH2_T_OFFSET = +0.0667`, bringing A−B to
within 0.1 mK. The data, statistics and Allan deviation are in
[`calibration/calibration_run_results.md`](calibration/calibration_run_results.md).

## 3. Absolute calibration (optional)

If you also want the readings to be correct on a true temperature scale,
characterise each thermistor against a reference probe and fit the B-model, as
described in [`characterisation.md`](characterisation.md). That sets `CH*_B_VAL`
and `CH*_INTERCEPT` per channel. The matching trim from step 2 then sits on top
of it and still applies.

## Where each value lives in `config.py`

| Setting | What it does |
|---|---|
| `V_EXC` | measured excitation voltage |
| `CH*_R_TOP`, `CH*_R_A`, `CH*_R_B` | measured bridge resistors, set the recovered R |
| `CH*_B_VAL`, `CH*_INTERCEPT` (or `CH*_SH_*`) | the R-to-temperature model |
| `CH1_T_OFFSET`, `CH2_T_OFFSET` | the channel-matching trim from step 2 |

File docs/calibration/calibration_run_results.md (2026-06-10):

# Calibration run results

Channel-matching and differential-stability results from a single logged run with
both thermistor beads bonded together inside a temperature-controlled box. The
numbers and the plot below are ready to cite. The raw data is
[`calibration_log.csv`](calibration_log.csv) and the figure is
[`calibration_run_stability.png`](calibration_run_stability.png).

## Setup

- Both NTC beads bonded in firm thermal contact and placed in a
  temperature-controlled box, so they share one temperature.
- QUIET sampling profile: 16 averages, 8 SPS, PGA ±0.256 V, 5 s cycle.
- Captured over USB with `tools/serial_logger.py`.
- Date 2026-06-10. Duration 18.3 min, 219 samples at a sample period of 5.0 s.

## Statistics

| Series | Mean (°C) | Sigma (mK) | Peak-to-peak (mK) | Drift (mK/hr) |
|---|---|---|---|---|
| A (NTC-01) | 24.7480 | 53.60 | 190.5 | −583.5 |
| B (NTC-02) | 24.6145 | 51.41 | 194.3 | −558.4 |
| **A − B** | **0.1335** | **3.02** | **22.5** | **−25.1** |

The box temperature drifted about 190 mK over the run, and both probes followed
it together (their absolute drifts agree to within 4 mK). That common drift
cancels in A − B, whose sigma is roughly 18 times smaller than either channel
alone (3.0 mK against ~53 mK). This is the common-mode rejection of the matched
differential bridge in action.

## Channel offset (the calibration)

A read +133.5 mK above B, and the difference stayed flat to a few mK as the box
drifted. Split symmetrically between the two channels, the matching trim is

```
CH1_T_OFFSET = -0.0667    # NTC-01 (A)
CH2_T_OFFSET = +0.0667    # NTC-02 (B)
```

now set in [`../../firmware/config.py`](../../firmware/config.py). Applying these
to this run brings the measured A − B from +133.5 mK down to +0.1 mK, so the two
channels agree to within 0.1 mK.

## Overlapping Allan deviation

| Averaging time tau (s) | A (mK) | B (mK) | A − B (mK) |
|---|---|---|---|
| 5 | 0.87 | 0.76 | 0.53 |
| 10 | 1.62 | 1.51 | 0.83 |
| 15 | 2.39 | 2.24 | 1.10 |
| 20 | 3.17 | 2.96 | 1.32 |
| 30 | 4.70 | 4.35 | 1.47 |
| 40 | 6.20 | 5.69 | 1.30 |
| 55 | 8.29 | 7.60 | 1.13 |
| 75 | 10.70 | 10.01 | 1.01 |
| 100 | 13.44 | 12.83 | 0.85 |
| 131 | 16.60 | 15.99 | 0.79 |
| 171 | 20.61 | 19.89 | 0.86 |
| 226 | 25.87 | 24.92 | 1.08 |
| 296 | 32.43 | 31.09 | 1.44 |
| 387 | 41.20 | 39.36 | 1.88 |
| 507 | 55.05 | 52.51 | 2.55 |

How to read the curve (see [`calibration_run_stability.png`](calibration_run_stability.png)):

- **Each channel alone (A, B) rises monotonically with tau**, so it is
  drift-limited. Averaging for longer does not help, because the box's absolute
  temperature is wandering. The per-channel Allan deviation is about 0.8 mK at a
  single sample and climbs past 50 mK by tau = 500 s as the drift accumulates.
- **The A − B difference stays sub-millikelvin across the whole range.** It is
  0.53 mK at a single sample, rises to about 1.5 mK near tau = 30 s, then settles
  to a broad minimum around 0.8 mK near tau = 130 s. The common-mode rejection
  buys roughly two orders of magnitude of stability in the difference channel.

This is the central result the instrument was built to demonstrate: a commodity
16-bit ADC in a matched differential bridge resolves temperature *differences* at
the sub-millikelvin level, even while the absolute temperature drifts by hundreds
of millikelvin.

## Per-probe short-term precision

Removing the box drift with successive differences (the standard short-term-noise
estimator) gives a single-sample noise of about **0.6 mK for probe A and 0.4 mK
for probe B** (1σ). This matches the A − B Allan deviation of 0.53 mK to better
than 0.01 mK, which is the cross-check that it is genuine sensor noise and not an
artefact. These are the per-probe precisions used independently. They are upper
bounds, because the box was still drifting, so the true floor is no worse than
this and approaches the theoretical ~85 µK (see
[`../error_budget.md`](../error_budget.md)). The resolution is 0.21 mK per ADC
count. Each probe's absolute accuracy is separate and reference-limited at
~0.1 °C.

## What this run does and does not show

- It **does** establish the channel matching, the per-probe short-term precision
  above, and the differential (A − B) stability floor of about 0.5 to 0.8 mK on
  real hardware.
- It **does not** pin the absolute single-channel stability. The box was still
  settling, so the per-channel absolute figures are drift-limited rather than a
  true noise floor. That floor is bounded by the thermal environment rather than
  the ADC, so characterising it further would need a reference more stable than
  the box used here.

For the theoretical floor these sit against, see
[`../error_budget.md`](../error_budget.md): resolution ~0.21 mK/LSB and a
white-noise floor well below 0.1 mK per sample.

## Reproduce

```
./run.sh analyse docs/calibration/calibration_log.csv
```

This prints the statistics and Allan deviation above and writes the plot.

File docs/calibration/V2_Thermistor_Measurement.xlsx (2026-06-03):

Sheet: Instructions
NTC Thermistor Calibration Template — How to Use
Purpose
Fit two models to each thermistor: the 2-parameter B model (R₀, B) and the 3-parameter Steinhart-Hart model (A, B, C). Plot of ln(R) vs 1/T should be a straight line with slope B. The Steinhart-Hart fit captures the mild curvature the B-model can't.
Procedure — thermal setup
1. Fill a small insulated water bath (a vacuum flask or stirred beaker on a hotplate works). Bond the two thermistors together with your reference probe (multimeter temp probe or DS18B20) using a small blob of thermal compound wrapped in thin heat-shrink or PTFE tape. Goal: identical thermal mass touching the same water. 2. Stir continuously — unstirred water can have several-°C gradients between the probe and the thermistor only centimetres away. A small aquarium pump or magnetic stirrer is perfect. 3. Start cold (ice slurry, not just cold tap water — crushed ice + water gives a rock-solid 0.0 °C plateau for ~10 minutes). Then work upward: 10, 20, 30, 40, 50, 60, 70, 80 °C. You can drop points if you're short on time — eight good points is plenty. 4. At each set-point, wait until BOTH the reference reading and the thermistor
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

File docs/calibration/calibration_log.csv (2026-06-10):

0 | 4.49 | -12.2 | 100491.2 | 24.8717 | -7835.0 | 100697.5 | 24.7457 | 2026-06-10T10:55:40.992
1 | 9.42 | -23.4 | 100492.6 | 24.8714 | -7929.7 | 100709.1 | 24.7430 | 2026-06-10T10:55:45.920
2 | 14.43 | -41.5 | 100494.8 | 24.8709 | -8025.9 | 100720.9 | 24.7403 | 2026-06-10T10:55:50.930
3 | 19.44 | -35.6 | 100494.1 | 24.8711 | -8121.1 | 100732.6 | 24.7376 | 2026-06-10T10:55:55.940
4 | 24.46 | -59.6 | 100497.0 | 24.8704 | -8213.4 | 100743.9 | 24.7350 | 2026-06-10T10:56:00.956
5 | 29.48 | -69.3 | 100498.2 | 24.8701 | -8303.2 | 100754.9 | 24.7325 | 2026-06-10T10:56:05.981
6 | 34.50 | -65.9 | 100497.8 | 24.8702 | -8394.0 | 100766.1 | 24.7299 | 2026-06-10T10:56:11.002
7 | 39.52 | -69.3 | 100498.2 | 24.8701 | -8481.0 | 100776.8 | 24.7274 | 2026-06-10T10:56:16.015
8 | 44.53 | -84.0 | 100500.0 | 24.8697 | -8568.4 | 100787.5 | 24.7250 | 2026-06-10T10:56:21.023
9 | 49.53 | -160.6 | 100509.4 | 24.8675 | -8651.4 | 100797.7 | 24.7226 | 2026-06-10T10:56:26.057
10 | 54.54 | -152.8 | 100508.4 | 24.8677 | -8733.4 | 100807.8 | 24.7203 | 2026-06-10T10:56:31.033
11 | 59.54 | -197.3 | 100513.9 | 24.8665 | -8814.5 | 100817.7 | 24.7180 | 2026-06-10T10:56:36.037
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

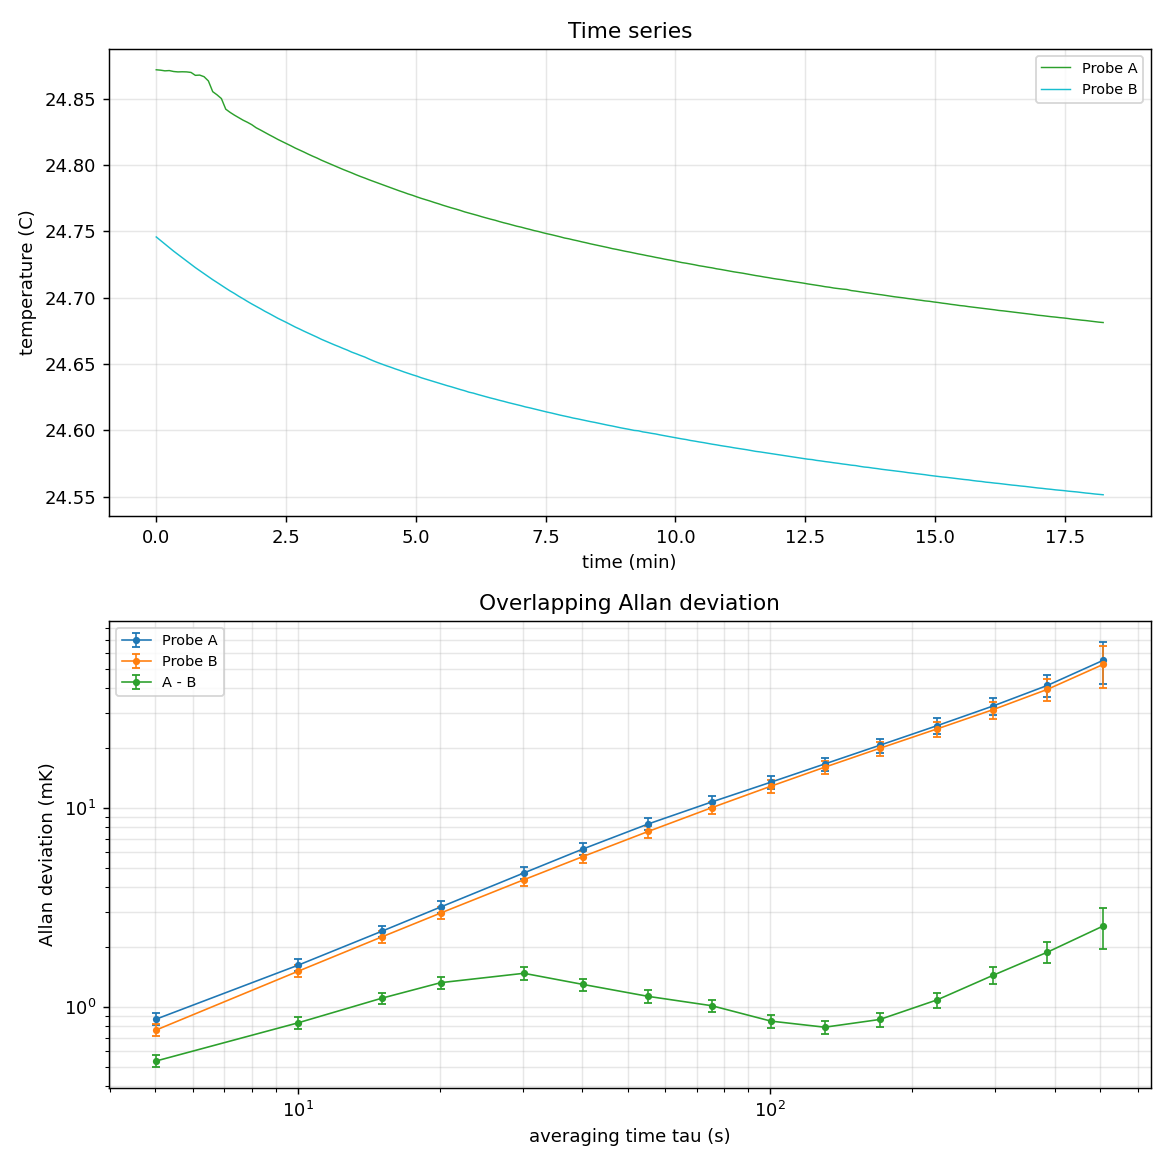
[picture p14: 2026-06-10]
docs/calibration/calibration_run_stability.png

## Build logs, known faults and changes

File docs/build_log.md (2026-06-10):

# Build log

Chronological bring-up, including the debugging dead-ends. They are kept because
they are the most useful part for anyone reproducing the work.

## 1. Front-end design

Differential half-bridge per probe, ADS1115 at PGA = 16 for 0.21 mK/LSB. Bridge
maths and resolution were verified by round-trip simulation before any hardware.

## 2. Single-channel breadboard bring-up

* First run with nothing wired: I²C scan empty, as expected. Added a
  wait-for-ADC loop so a missing board no longer crashes the session.
* With the ADS1115 wired, `0x48` was found and the self-check ran.
* **Dead-end #1: readings pinned at 100 kΩ, not tracking.** The thermistor's
  resistance changed at the jack but not in the readings. The cause was that the
  diagnostic script read the AIN0-AIN1 pair while the bridge was wired to
  AIN2-AIN3. The ADS1115 has two differential pairs and the MUX bits select
  between them. The fix was to point the MUX at the correct pair. Differential
  mode had been correct all along, it was just the wrong pair.
* After the fix the resistance tracked a finger-pinch up and down correctly. The
  front-end was proven.

## 3. Connectors

TRS audio jacks are used as thermistor connectors (Tip = sense node, Ring = GND,
Sleeve = shield grounded at the board end only). The thin inner conductors of
aux cable are enamelled, so they must be tinned or scraped before they make
contact. This initially looked like a broken cable.

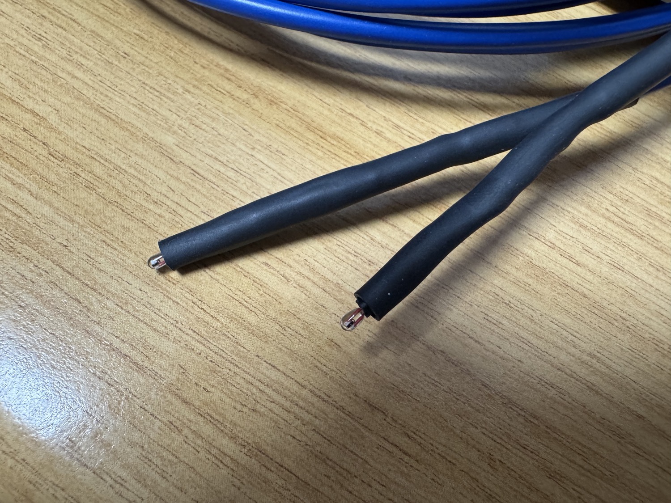
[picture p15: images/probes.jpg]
Thermistor probe leads, the enamelled inner conductors tinned and ready to terminate


## 4. Two-channel (Option C)

Both probes on independent differential pairs: CH1 = AIN0−AIN1,
CH2 = AIN2−AIN3. Thermistor A goes to CH1 and B goes to CH2, so each matches its
calibration coefficients.

## 5. Pulsed excitation attempt (abandoned)

* Built a high-side PMOS switch on the excitation rail.
* **Dead-end #2: bridge dead with the PMOS in circuit.** Drain stuck at 0 V. The
  gate measured swinging 3.3 V to 1.6 V and never reached 0 V. The cause was
  that the two-resistor gate "drive" was actually a passive divider that floats
  the gate to its midpoint, so it cannot pull a high-side PMOS gate to 0 V.
* Switched to direct GPIO gate drive (active-low). The gate then swung fully and
  the PMOS conducted.
* The catch was that the only available PMOS was an IRFD9024, a
  standard-threshold part. At −3.3 V V_GS it only partially enhances, dropping
  about 0.38 V with a temperature-dependent resistance. The decision was to
  remove the switch and run continuous excitation. Self-heating then becomes a
  constant, calibrated-out offset, which is cleaner than a drifting switch.
  Pulsing can return later with a logic-level PMOS.

## 6. Thermistor characterisation

UT71B sweep, B-model fit for the 10 to 30 °C operating range. Coefficients were
entered in config and the firmware conversion was verified against the fit's own
predictions.

## 7. Soldered to stripboard

* Added RC input filters and star grounding.
* **Dead-end #3: huge readings after soldering.** The self-check showed Vdiff of
  about −1.59 V on both channels, where it should be tens of mV. A software
  sign-invert turned it positive but the magnitude stayed at about 1.59 V, so
  the real fault was not a sign swap but a node sitting near a rail (a mis-wired
  or open input on the soldered board, found by measuring each AIN pin to GND).
  The lesson is that a large differential means a node is not at a divider
  midpoint, so measure the pins before touching firmware.

## 8. Multi-page UI

LIVE, TREND, DELTA and STATS pages, joystick navigation, backlight control,
rolling σ and drift, and a STABLE/SETTLING flag. The logic was verified in a
desktop simulation with mocked hardware.

## 9. UI and host-logging rework

* **Dead-end #4: paging felt unreliable.** The display module had at some point
  been pasted into its own file twice. Python kept the second copy, and that copy
  navigated only with the joystick LEFT and RIGHT, which are the least dependable
  inputs on the HAT. Removing the duplicate and moving paging onto the two
  physical keys (KEY A next, KEY B previous, joystick LEFT and RIGHT as a backup)
  fixed it.
* Enlarged the on-screen text and re-laid-out every page so nothing overlaps,
  after spotting the rolling σ field colliding with the cycle counter and the
  STATS span and drift line running off the right edge.
* Added an AVERAGES page (rolling mean over a short and a long window per probe)
  and a runtime QUIET/FAST sampling switch on a long-press of the joystick
  centre, so the sampling cadence can change without a reflash.
* Added `tools/serial_logger.py` to capture the USB CSV stream straight onto the
  host computer. The page layouts and the button logic were checked in desktop
  simulations with mocked hardware before flashing.

## 10. Channel matching and first Allan deviation

Both beads were bonded and logged in a temperature-controlled box. Both probes
followed the box drift together (about 190 mK, agreeing to within 4 mK), so the
A−B difference sat flat at +133.5 mK. That offset was split between the two
channels (`CH1_T_OFFSET`, `CH2_T_OFFSET`) to bring A−B to within 0.1 mK. The same
run gave the first overlapping Allan deviation: each channel alone is
drift-limited, but A−B stays sub-millikelvin (about 0.5 to 0.8 mK), which is the
common-mode rejection the differential bridge was built for. Full write-up in
[`calibration/calibration_run_results.md`](calibration/calibration_run_results.md).

## Outcome

The bonded-probe run answered the central question: a commodity 16-bit ADS1115 in
a matched differential bridge resolves temperature differences at the
sub-millikelvin level, so the more expensive 24-bit ADS1220 is not needed for this
application. The absolute single-channel stability is bounded by the thermal
environment rather than the ADC, and characterising it further would need a more
stable reference than was available. Possible extensions are in the README's
future-improvements section.

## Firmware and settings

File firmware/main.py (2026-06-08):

# =============================================================================
# main.py  --  The Box temperature-sensor PoC.  Runs on the Pico W.
#
# Cycle:  pulse bridge ON -> settle -> read CH1 & CH2 differentially ->
#         pulse OFF -> convert to R and T -> read DS18B20 -> update LCD ->
#         log CSV -> sleep for the rest of the cycle period.
#
# Files this depends on (copy all to the Pico):
#   config.py  ads1115.py  bridge.py  ds18b20_reader.py  display.py
#   (and, for the screen, Waveshare's lcd_1inch14.py)
# =============================================================================
from machine import Pin, I2C
import time

import config
from ads1115 import ADS1115
from bridge import Channel
import display
import sampling

# Optional DS18B20
ds = None
if config.USE_DS18B20:
    try:
        from ds18b20_reader import DS18B20
        ds = DS18B20(config.PIN_ONEWIRE)
        if not ds.present:
            print("[ds18b20] no sensor found on bus; continuing without it.")
            ds = None
    except Exception as e:
        print("[ds18b20] init failed (%s); continuing without it." % e)
        ds = None


def _pick(override, default):
    return default if override is None else override


_CSV_HEADER = ("cycle,t_s,vdiff1_uv,r1_ohm,t1_c,"
               "vdiff2_uv,r2_ohm,t2_c,t_amb_c")


def _flash_log_init():
    """Open the flash log for appending; write a header if the file is new.
    Returns an open file handle, or None if logging to flash is off/failed."""
    if not config.LOG_TO_FLASH:
        return None
    try:
        import os
        new = True
        try:
            if os.stat(config.LOG_FILENAME)[6] > 0:   # size > 0 => existing
                new = False
        except OSError:
            new = True
        fh = open(config.LOG_FILENAME, "a")
        if new:
            fh.write(_CSV_HEADER + "\n")
            fh.flush()
        return fh
    except Exception as e:
        print("[flash] logging disabled (%s)" % e)
        return None


def _flash_size():
    try:
        import os
        return os.stat(config.LOG_FILENAME)[6]
    except Exception:
        return 0


def build_channels():
    ch1 = Channel(
        "CH1", config.V_EXC,
        _pick(config.CH1_R_TOP, config.R_TOP),
        _pick(config.CH1_R_A,   config.R_A),
        _pick(config.CH1_R_B,   config.R_B),
        model=config.TEMP_MODEL,
        b_val=config.CH1_B_VAL, intercept=config.CH1_INTERCEPT,
        sh_a=config.CH1_SH_A, sh_b=config.CH1_SH_B, sh_c=config.CH1_SH_C,
        t_offset=config.CH1_T_OFFSET)
    ch2 = Channel(
        "CH2", config.V_EXC,
        _pick(config.CH2_R_TOP, config.R_TOP),
        _pick(config.CH2_R_A,   config.R_A),
        _pick(config.CH2_R_B,   config.R_B),
        model=config.TEMP_MODEL,
        b_val=config.CH2_B_VAL, intercept=config.CH2_INTERCEPT,
        sh_a=config.CH2_SH_A, sh_b=config.CH2_SH_B, sh_c=config.CH2_SH_C,
        t_offset=config.CH2_T_OFFSET)
    return ch1, ch2


def bridge_on(pulse_pin):
    if not config.USE_PULSED_EXCITATION or pulse_pin is None:
        return                      # continuous excitation: always on, nothing to do
    pulse_pin.value(0 if config.PULSE_ACTIVE_LOW else 1)


def bridge_off(pulse_pin):
    if not config.USE_PULSED_EXCITATION or pulse_pin is None:
        return                      # continuous excitation: leave bridge powered
    pulse_pin.value(1 if config.PULSE_ACTIVE_LOW else 0)


def main():
    # --- bring up hardware ---
    i2c = I2C(config.I2C_ID,
              sda=Pin(config.PIN_SDA),
              scl=Pin(config.PIN_SCL),
              freq=config.I2C_FREQ)

    found = i2c.scan()
    print("[i2c] devices:", [hex(a) for a in found])

    # --- wait (don't crash) until the ADS1115 actually appears on the bus ---
    # Lets you hot-wire the board and have it pick up without re-running.
    if config.USE_PULSED_EXCITATION:
        pulse = Pin(config.PIN_PULSE, Pin.OUT)
        pulse.value(1 if config.PULSE_ACTIVE_LOW else 0)   # bridge OFF before we have `adc`
    else:
        pulse = None                                       # continuous: no switch

    while config.ADS_ADDR not in i2c.scan():
        print("[i2c] waiting for ADS1115 @ 0x%02x ... "
              "(check SDA/SCL, VDD, GND, pull-ups, ADDR->GND)" % config.ADS_ADDR)
        display.message("Waiting for", "ADS1115...")
        time.sleep(1)
    print("[i2c] ADS1115 found.")

    active_prof = sampling.current()
    adc = ADS1115(i2c, addr=config.ADS_ADDR,
                  fsr=active_prof["fsr"], datarate=active_prof["datarate"])
    adc.invert_ch1 = config.INVERT_CH1
    adc.invert_ch2 = config.INVERT_CH2

    bridge_off(pulse)            # start with bridge de-energised
    ch1, ch2 = build_channels()

    # --- one-shot startup self-check: energise, read both channels, report ---
    # Wrapped so a transient I2C glitch reports instead of crashing the session.
    print("[selfcheck] energising bridge for range check...")
    try:
        bridge_on(pulse)
        time.sleep_ms(config.SETTLE_MS)
        sv1 = adc.read_diff(1)
        sv2 = adc.read_diff(2)
        bridge_off(pulse)
        for name, sv in (("CH1", sv1), ("CH2", sv2)):
            status = "CLIPPING - check NTC R or PGA" if adc.near_clip(sv) else "in range"
            print("[selfcheck] %s Vdiff = %+.4f V  (%s)" % (name, sv, status))
        if adc.near_clip(sv1) or adc.near_clip(sv2):
            display.message("Bridge OUT OF", "RANGE - see USB")
            time.sleep(2)
    except OSError as e:
        bridge_off(pulse)
        print("[selfcheck] I2C error during self-check (%s); "
              "continuing into main loop." % e)

    # CSV header over USB serial
    if config.LOG_TO_CONSOLE:
        print(_CSV_HEADER)

    # Flash log (append mode; survives USB disconnect)
    flash = _flash_log_init()
    flash_full = False
    if flash:
        print("[flash] logging to %s" % config.LOG_FILENAME)

    cycle = 0
    consecutive_errs = 0
    t_start = time.ticks_ms()

    while True:
        cycle_t0 = time.ticks_ms()

        # --- apply a live QUIET/FAST profile switch requested from the display ---
        prof = sampling.current()
        if prof is not active_prof:
            try:
                adc.reconfigure(fsr=prof["fsr"], datarate=prof["datarate"])
                active_prof = prof
                print("[mode] %s: %d avg, %d SPS, +-%.3f V, %.1f s cycle"
                      % (prof["name"], prof["n_avg"], prof["datarate"],
                         prof["fsr"], prof["period_s"]))
            except OSError as e:
                print("[mode] reconfigure failed (%s); keeping previous." % e)

        # Kick off DS18B20 conversion early so its 750 ms overlaps our work.
        if ds:
            ds.start()

        # --- energise bridge and let it settle (per-profile settle wait) ---
        bridge_on(pulse)
        time.sleep_ms(prof.get("settle_ms", config.SETTLE_MS))

        # --- read both differential channels (averaged) ---
        # poll=display.tick keeps the buttons and screen responsive during the
        # read, which in the QUIET profile takes about 4 s.
        try:
            v1, _ = adc.read_diff_avg(1, prof["n_avg"], poll=display.tick)
            v2, _ = adc.read_diff_avg(2, prof["n_avg"], poll=display.tick)
            consecutive_errs = 0
        except OSError as e:
            bridge_off(pulse)
            consecutive_errs += 1
            print("[loop] I2C error (%s) on cycle %d (x%d); skipping."
                  % (e, cycle, consecutive_errs))
            # After several straight failures, try to re-init the bus once.
            if consecutive_errs in (5, 20, 50):
                print("[loop] attempting I2C bus re-init...")
                try:
                    i2c.init(scl=Pin(config.PIN_SCL), sda=Pin(config.PIN_SDA),
                             freq=config.I2C_FREQ)
                except Exception as ie:
                    print("[loop] re-init failed (%s)" % ie)
            time.sleep(1)
            continue

        # --- de-energise bridge (minimise self-heating) ---
        bridge_off(pulse)

        # --- convert ---
        r1, t1 = ch1.convert(v1)
        r2, t2 = ch2.convert(v2)

        # --- ambient (result of the conversion we started at top of loop) ---
        t_amb = None
        if ds:
            # ensure the 750 ms conversion has finished, polling the UI meanwhile
            while time.ticks_diff(time.ticks_ms(), cycle_t0) < 800:
                display.tick()
                time.sleep_ms(20)
            t_amb = ds.read()

        # --- display: push new data, then poll UI during cooldown ---
        display.push(t1, r1, t2, r2, t_amb, cycle)

        # --- build the CSV line once ---
        t_s = time.ticks_diff(time.ticks_ms(), t_start) / 1000.0
        def f(x, nd=3):
            return "" if x is None else ("{:.%df}" % nd).format(x)
        line = "{},{:.2f},{},{},{},{},{},{},{}".format(
            cycle, t_s,
            f(v1 * 1e6, 1), f(r1, 1), f(t1, 4),
            f(v2 * 1e6, 1), f(r2, 1), f(t2, 4),
            f(t_amb, 3))

        if config.LOG_TO_CONSOLE:
            print(line)

        if flash and not flash_full:
            try:
                flash.write(line + "\n")
                flash.flush()                      # flush so a reset keeps data
                if _flash_size() >= config.LOG_MAX_BYTES:
                    flash_full = True
                    print("[flash] %s reached %d bytes; stopping flash log."
                          % (config.LOG_FILENAME, config.LOG_MAX_BYTES))
            except Exception as e:
                print("[flash] write error (%s); disabling flash log." % e)
                flash = None

        cycle += 1

        # --- responsive cooldown: poll joystick / redraw ~25 Hz until next cycle ---
        deadline = time.ticks_add(cycle_t0, int(prof["period_s"] * 1000))
        while time.ticks_diff(deadline, time.ticks_ms()) > 0:
            display.tick()
            time.sleep_ms(40)


if __name__ == "__main__":
    main()

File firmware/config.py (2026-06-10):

# =============================================================================
# config.py  --  ALL tunable values live here.
#
# This is the ONLY file that differs between the breadboard build and the
# final Veroboard build.  Debug everything on the breadboard, then for the
# Veroboard you only revisit the marked sections (pins / timing / calibration).
# =============================================================================

# -----------------------------------------------------------------------------
# 1. I2C / ADS1115
# -----------------------------------------------------------------------------
I2C_ID       = 0          # Pico I2C0 peripheral
PIN_SDA      = 0          # GP0 -> ADS1115 SDA
PIN_SCL      = 1          # GP1 -> ADS1115 SCL
I2C_FREQ     = 400_000    # 400 kHz standard fast-mode
ADS_ADDR     = 0x48       # ADDR pin tied to GND -> 0x48

# Input-polarity correction. A warm-the-probe test showed the NTC resistance
# rising when heated, but it must fall, so the earlier inversion was backwards.
# The board is in fact wired correctly (node A on AINP, node B on AINN). The
# static room-temperature match that set these True was a false positive: a
# plausible resistance sitting on an inverted slope. Flags off give the correct
# slope. Set True only if the inputs are physically swapped.
INVERT_CH1   = False
INVERT_CH2   = False

# -----------------------------------------------------------------------------
# 2. Pulsed-excitation switch (PMOS high-side)
#    GP22 LOW  = bridge ON   (PMOS conducting)
#    GP22 HIGH = bridge OFF
# -----------------------------------------------------------------------------
# -----------------------------------------------------------------------------
# 2. Bridge excitation
#
#    USE_PULSED_EXCITATION = False  -> bridge tops wired straight to 3V3 (or a
#    series-dropper resistor).  No switch.  GP22 is not used.  Self-heating is a
#    constant offset that calibrates out -- correct choice without a logic-level
#    PMOS.  Set True only if a proper logic-level PMOS switch is fitted.
# -----------------------------------------------------------------------------
USE_PULSED_EXCITATION = False
PIN_PULSE        = 22         # GP22 -> PMOS gate (only used if pulsed)
PULSE_ACTIVE_LOW = False      # only relevant if USE_PULSED_EXCITATION = True
SETTLE_MS        = 50         # settle wait before converting (used in both modes)
OFF_SETTLE_MS    = 50         # (pulsed mode only)

# -----------------------------------------------------------------------------
# 3. DS18B20 (1-Wire)
# -----------------------------------------------------------------------------
PIN_ONEWIRE  = 4          # GP4 -> DS18B20 DQ (with 4k7 pull-up to 3V3)
USE_DS18B20  = False      # set False if probe not plugged in

# -----------------------------------------------------------------------------
# 4. LCD (Waveshare Pico-LCD-1.14, ST7789).  Pins fixed by the HAT.
# -----------------------------------------------------------------------------
USE_LCD      = True
PIN_LCD_SCK  = 10
PIN_LCD_MOSI = 11
PIN_LCD_CS   = 9
PIN_LCD_DC   = 8
PIN_LCD_RST  = 12
PIN_LCD_BL   = 13
LCD_SPI_ID   = 1

# Joystick + buttons on the Pico-LCD-1.14 HAT (active-low, internal pull-ups)
PIN_JOY_UP    = 2
PIN_JOY_DOWN  = 18
PIN_JOY_LEFT  = 16
PIN_JOY_RIGHT = 20
PIN_JOY_CTRL  = 3
PIN_KEY_A     = 15
PIN_KEY_B     = 17

# Display behaviour
DISPLAY_BYTESWAP = True    # flip if on-screen colours look wrong (RGB565 order)
LABEL_A      = "A"         # rename to "IN" / "FIBRE" / etc. as you like
LABEL_B      = "B"         # rename to "OUT" / "AIR" / etc.
STATS_WINDOW = 32          # samples used for rolling mean / sigma
SETTLE_SIGMA_MK = 5.0      # rolling sigma below this (mK) => "STABLE"

# -----------------------------------------------------------------------------
# 5. Bridge electrical model
#
#    Half-bridge per channel:
#         V_EXC --- R_top --- NODE_B --- NTC --- GND      (sense leg)
#         V_EXC --- R_a   --- NODE_A --- R_b  --- GND      (reference leg)
#    ADC reads  Vdiff = V(NODE_A) - V(NODE_B)   (AINP - AINN)
#
#    With all reference resistors equal to R_REF and excitation V_EXC:
#         V(NODE_A) = V_EXC * R_b / (R_a + R_b)      (fixed, = V_EXC/2 if equal)
#         V(NODE_B) = V_EXC * NTC / (R_top + NTC)
#    Solve the measured Vdiff for NTC.  Because the ADS1115 is *ratiometric-ish*
#    only (internal ref), we still need V_EXC numerically -- measure it once with
#    your multimeter and put it here.
# -----------------------------------------------------------------------------
V_EXC        = 3.284      # measured at the bridge top node
R_TOP        = None       # per-channel overrides used instead (see below)
R_A          = None
R_B          = None
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

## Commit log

2026-06-02 Added Box CAD files
    [cover.f3d, cover.step, cover.stl]
2026-06-03 Add photos, calibration workbook, and KiCad schematic
    [ADS1115BasicDesign.csv, ADS1115BasicDesign.kicad_sch, V2_Thermistor_Measurement.xlsx]
2026-06-03 Fix inverted channel polarity (turn off invert flags)
    [config.py]
2026-06-08 Enlarge screen text, fix overlaps, reliable KEY A/B paging
    [display.py]
2026-06-08 Fix delta-axis overrun, ambient/cycle overlap, backlight order
    [display.py]
2026-06-08 Add per-channel temperature trim for matching probes
2026-06-08 Document calibration procedure and channel matching
2026-06-08 Speed up FAST profile to about 5 Hz
2026-06-09 Set CH2_R_B to measured 99111 ohm
2026-06-10 Add pull-log and clear-log commands for the Pico flash log
2026-06-10 run.sh: virtualenv fallback for setup, reset Pico after log ops
2026-06-10 calibration log
    [calibration_log.csv]
2026-06-10 Set channel-matching offsets from bonded-probe calibration run
2026-06-10 Add calibration run results, Allan write-up and stability plot
2026-06-10 Document calibration findings across docs; correct degree to MSc
2026-06-10 Quantify per-probe single-channel precision (0.4 to 0.6 mK)
2026-06-11 Updates to cover
    [cover.f3d, cover.step, cover.stl]
2026-06-11 Update README for CAD cover
    Updated the CAD file date.
